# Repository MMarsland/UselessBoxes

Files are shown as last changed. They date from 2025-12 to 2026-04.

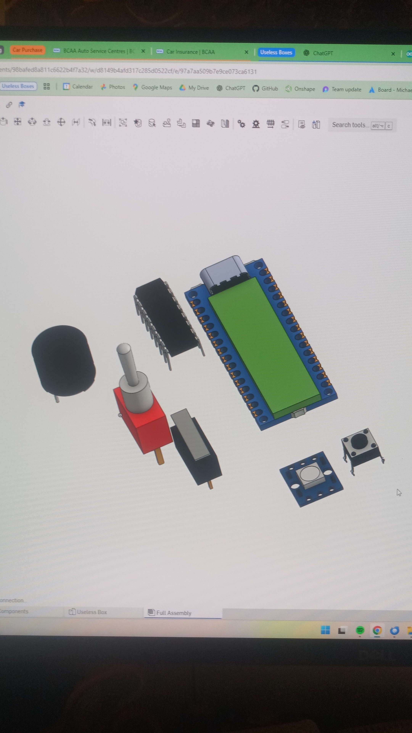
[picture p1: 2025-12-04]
docs/Publicity Images/IMG_20251023_234716_154.jpg

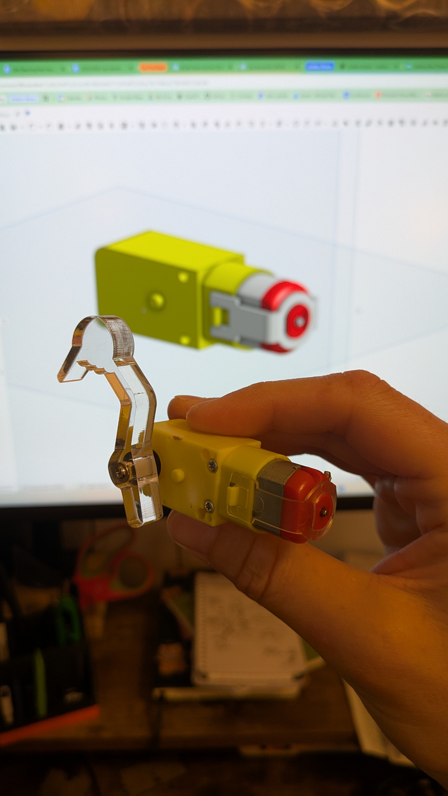
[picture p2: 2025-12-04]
docs/Publicity Images/PXL_20251024_221917552.jpg

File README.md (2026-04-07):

# 🟢 Project: UselessBoxes

A design for paired **UselessBoxes** that can be used to interact between friends.

---





---

## 📅 Project Info

- **Author:** Michael Marsland
- **Email:** mmarsland@mac.com
- **Date:** 10/10/2025
- **Revision:** 01/09/2026 - Alpha Dev
- **License:** Proprietary

**Project Description:**

The Useless Box project started a few years ago when my friend Trevor Johns gifted me a "Useless Box" for my birthday. A "Useless Box" is simply a small electro-mechanical device that sits on your desk and has a single switch on top. Upon flicking the switch, a small arm rises from the box to de-activate the switch, and then the cycle repeats.

This gift inspired the idea for a small IoT project where I could build Trevor and I each a similarly "Useless Box" for our desks except with the main change being, my switch would activate his arm to flick his switch off, and him turning his switch on would activate the arm on my box to turn my switch off.

Of course, I also took the opportunity to improve on the design of the box, adding LEDs, buzzers, settings buttons, and a sleeker look to make us the perfect desktop interactive toys. So while we're busy working on our other projects be it for work or personal interest, Trevor and I will be able to maintain our connection across the internet and still get on each others nerves even though we don't live in the same city anymore.

This project has been in the works for quite a while now and it is now in the late stages of assembly as I prepare to have it ready for his birthday this year (End of December).

I would like to see this project grow after the development of this first prototype so Trevor and I may collaborate on more iterations and maybe even add some of our other friends and create a larger interconnected network of slightly less useless "Useless Boxes" to all bother each other at once!

Let me know what you think and stay tuned for more updates!

---

## 🛠 Step 1: Installation

Currently using **Arduino Cloud** to set up the device as a "Thing" and a dashboard to control and monitor the variables.

### For Development:

I am currently developing in VSCode using the PlatformIO extension. I started in the ArduinoCloud Editor, and then copied UselessBoxes.ino, thingProperties.h, and arduino_secrets_*.h from there into my local ArduinoIDE. Then I installed all the required libraries from the ArduinoIDE (ArduinoIoTCloud, etc...), then I was able to make a project in PlatformIO in VS code and copy over the files. The modifications you must make to get it building in PlatformIO are:

1. Add these lines to platformio.ini
   ```
   lib_extra_dirs = ~/Documents/Arduino/libraries
   lib_ignore = WiFiNINA
   ```
2. Change Useless_Boxes.ino to Useless_Boxes.cpp
3. Write a "Useless_Boxes.h" with variable and function definitions (Ask an LLM for the header from the .cpp file)
4. Include `<Arduino>` and "Useless_Boxes.h" in Useless_Boxes.cpp
5. Include "arduino_secrets_*.h" in thingProperties.h

When running the code from this repository, all you should need to do is clone the repo, and then ensure you have Arduino ESP32 Boards by Arduino (2.0.18-arduino.5) installed in the ArduinoIDE, and the ArduinoIoTCloud by Arduino (2.8.0) library installed. Once these (And all dependencies) are installed in the ArduinoIDE, the project should build with PlatformIO in VSCode (Knock on Wood)

For Over The Air Uploads for new versions, follow this guide:

[Over The Air Uploads](./ota/ota-how-to-make-a-new-release.md)

---

## ⚡ Step 2: Assemble the Circuit

### 🧩 Components

- Arduino Nano ESP32 (3.3V logic)
- L293DNE H-Bridge motor driver
- DC motor
- SPDT switch (for direction)
- Momentary push button (for stop)
- 6V DC input (Potentially not necessary if USB-C power proves to be stable enough (Version 2))
- Jumper wires
- Common GND for all components

### ⚙️ Wiring Connections

## Useless Box Wiring Connections

## 🧠 Arduino Nano ESP32

| Pin | Connected To | Purpose / Notes |
| --- | --- | --- |
| **D2**  | L293D**Pin 2 (IN1)** | Motor direction control A (digital OUT).  |
| **D3**  | L293D**Pin 7 (IN2)** | Motor direction control B (digital OUT).  |
| **D4**  | L293D**Pin 1 (EN1)** | Motor enable / PWM speed control. |
| **D5**  | RGB LED**Blue** → 220Ω → LED **B Pin** | Blue channel (PWM). |
| **D6**  | RGB LED**Green** → 220Ω → LED **G Pin** | Green channel (PWM). |
| **D7**  | RGB LED**Red** → 220Ω → LED **R Pin** | Red channel (PWM). |
| **D8**  | SPDT Switch**Throw A** | Reads switch position (`INPUT_PULLUP`). |
| **D9**  | Limit Switch**NC Terminal** | Reads limit state (`INPUT_PULLUP`). |
| **D10** | Button**NC Terminal** | Reads button press (`INPUT_PULLUP`). |
| **D11** | Buzzer**+ Pin** | Buzzer output (tone / PWM). |
| **3V3** | — | Not used. |
| **GND** | All grounds (switches, LED common, buzzer −, L293D GND) | Shared ground. |

## 🐜 L293DNE (H-Bridge)

| L293D Pin | Function | Connected To | Notes |
| --- | --- | --- | --- |
| **Pin 1 (EN1)** | Enable 1 | Arduino**D4**  | PWM motor control  |
| **Pin 2 (IN1)** | Input 1 | Arduino**D2**  | Direction A |
| **Pin 7 (IN2)** | Input 2 | Arduino**D3**  | Direction B |
| **Pin 3 (OUT1)** | Motor A | Motor Terminal 1 | — |
| **Pin 6 (OUT2)** | Motor B | Motor Terminal 2 | — |
| **Pin 4, 5, 12, 13** | GND | Arduino**GND** | Common ground |
| **Pin 8 (VCC2)** | Motor Power | +6V external | Motor supply |
| **Pin 16 (VCC1)** | Logic Power | +5V supply | L293D logic supply |

## 🔀 SPDT Switch (2-position)

| Switch Terminal | Connected To | Purpose |
| --- | --- | --- |
| **Common (C)** | GND | Provides LOW when selected |
| **Throw A** | Arduino**D8** | Reads switch state |
| **Throw B** | — | Unused |

## 🧱 Limit Switch (Momentary)

| Terminal | Connected To | Purpose |
| --- | --- | --- |
| **C**  | GND | LOW when triggered |
| **NC** | Arduino**D9** (INPUT_PULLUP) | Default connected → LOW when limit reached |
| **NO** | — | Not used |

## 🔘 Button (Momentary)

| Terminal | Connected To | Purpose |
| --- | --- | --- |
| **C**  | GND | Pulls LOW when pressed |
| **NC** | Arduino**D10** (INPUT_PULLUP) | Reads button press |
| **NO** | — | Not used |

## 🔊 Buzzer

| Buzzer Pin | Connected To | Purpose |
| --- | --- | --- |
| **+**  | Arduino**D11** | Output for tone/PWM |
| **–** | GND | — |

## 🌈 RGB LED (Common Cathode recommended)

Each color pin requires a **220Ω resistor**.

| LED Pin | Connected To | Notes |
| --- | --- | --- |
| **R (Red)** | 220Ω → Arduino**D7** | PWM capable  |
| **G (Green)** | 220Ω → Arduino**D6** | PWM capable  |
| **B (Blue)** | 220Ω → Arduino**D5** | PWM capable  |
| **Common Cathode** | 3.3v | Shared power |

---

## 💻 Step 3: Load the Code

Upload the code contained in this sketch onto your board via PlatformIO in VSCode

### 📂 Folder Structure

- [README.md](README.md) — Project README and Instructions (This File)
- [.gitignore](.gitignore) — Git Ignore
- [sketch.json](sketch.json) — Something to do with Arduino Cloud
- [docs/](docs/) — Documentation Folder (Schematics)

  - [UselessBoxes.fzz](docs/UselessBoxes.fzz) — Fritzing Circuit Diagram
- [Useless_Boxes/](Useless_Boxes/) — Arduino sketch folder

  - [Useless_Boxes.ino](Useless_Boxes/Useless_Boxes.ino) — Main Arduino file
  - [arduino_secrets.h](Useless_Boxes/arduino_secrets.h) — Secrets for the Devices and Arduino Cloud
  - [thingProperties.h](Useless_Boxes/thingProperties.h) — Properties for Arduino Cloud

---

## 🤝 Contributing

To contribute to this project, please contact:

**Michael Marsland**
Email: mmarsland@mac.com

---

## 📝 Bill of Materials (BOM) (TODO)

| ID | Part name | Part number | Quantity |
| -- | --- | --- | --- |
| | Arduino Nano ESP32 | | 1 |
| | RGB Led | | 1 |
| | 220 Ohm Resistors | | 3 |
| | Piezo Buzzer | XYDZ | 1 |
| | Button | | 1 |
| | Limit Switch | | 1 |
| | SPDT Switch | | 1 |
| | H-Bridge | L293DE | 1 |
| | Barrel Jack Connector (Optional) | | 1 |
| | Motor, Gear Box, and Armature from Useless Box | | 1 |
| | 6V/0.83A Power Supply (Optional) | | 1 |
| | Wires (Approx 25) | | ~25 |
| | M2x6 Bolts & M2 Nuts | | 6 |
| | Custom 3D Printed Housing | | 1 |
| | | | |
| | | | |

---

## 🛣️ Project Roadmap

A step-by-step roadmap to finish the UselessBoxes project, from platform selection to final hardware.

### 🖥️ SOFTWARE

#### Decide on the Interconnection Platform

- Evaluate options:
  - Arduino Cloud
  - Thinger.io
  - Your own website with custom backend
- Consider:
  - Free tier limitations
  - Data synchronization capabilities
  - Ease of integration with Arduino Nano ESP32

**Decided to stick with Arduino Cloud for V1**
It will highly simplify the steps required to get a functioning system running.
And it will be free for up to two devices and 5 variables per device.
This should be enough to control the motors and even a few settings.
I can also determine a way to adjust settings on the device (A button perhaps and detailed procedures).
I can upgrade from Arduino Cloud to a different free option in the future such as using my website or a serverless implementation in V2.

#### Ensure Interdevice Communication and Functionality

* [X] Test interactions between paired UselessBoxes
* [X] Verify:
  * [X] State changes propagate correctly
  * [X] Motors respond as expected
  * [X] Dashboard reflects real-time updates

### ⚙️ HARDWARE

#### Design Hardware

* [X] Will need to decide on final wiring, how will the wires connect, where/how will the eletronics be seated
* [X] Prototype and design 3D printed housing
* [X] Ensure components can fit and function
* [X] Make design simple, and practical for desk use

#### Solder Components

* [X] Power Jack
* [X] Switch
* [X] Limit Switch
* [X] Buzzer
* [X] LED
* [X] H-Bridge
* [X] Button
* [X] Motor

##### Solder to Arduino

* [X] Power Jack
* [X] Switch
* [X] Limit Switch
* [X] Buzzer
* [X] LED
* [X] H-Bridge
* [X] Button
* [X] Solder all power to jack
* [X] Solder all ground to jack

#### Finalize Hardware

* [X] Secure all components in the box
* [X] Ensure wiring is neat and safe
* [X] Test full functionality before duplicating

#### Build the Second Box

* [X] Replicate hardware and software setup
* [X] Connect to the same platform
* [X] Test intercommunication between the two boxes

#### Tweaks / Features

* [X] Print and assemble final box in V5 with correct color
* [X] Ensure the correct state is loaded when turning on the box (I.e. LED)
* [X] Update munu items as we scroll through them
* [X] Play Buzzer sound Previews as we scroll through them (Loop should end quickly)
* [X] Make the menu navigation obvious with beeps or lights
* [ ] Add more buzzer and led patterns (+ make it easy and modular to add more custom buzzer and led patters)
* [ ] Clean up code (Organize where variables and defaults are declared)

#### Deployment Features

* [X] (Optional) Setup Over-The-Air updates so the software can be modified
* [X] Setup wifi connection process so that devices can be easily set up

##### ✅ Notes

- Based on testing, it appears the motor can run on board USB-C power without crashing the board so the 6V barrel jack source could be dropped in Version 2 and the whole box could be powered solely with the USB-C cable.

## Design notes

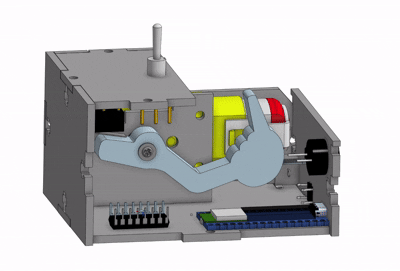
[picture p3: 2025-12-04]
docs/Publicity Images/OnShape Useless Box Video.gif

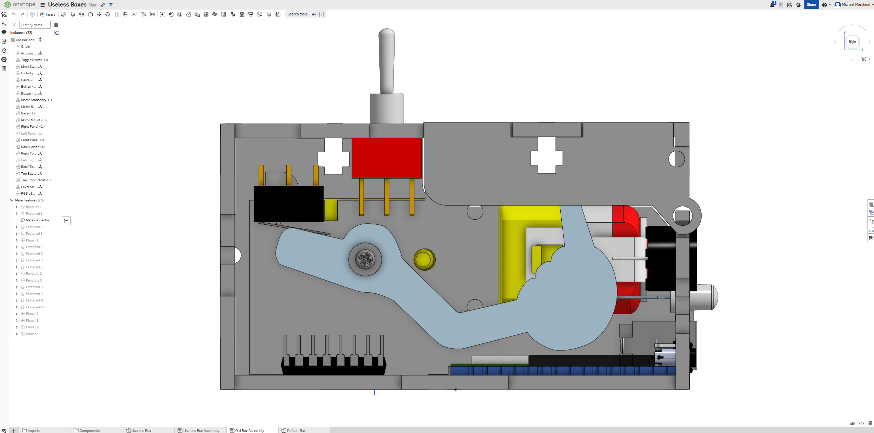
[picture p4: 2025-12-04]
docs/Publicity Images/Onshape Useless Box.png

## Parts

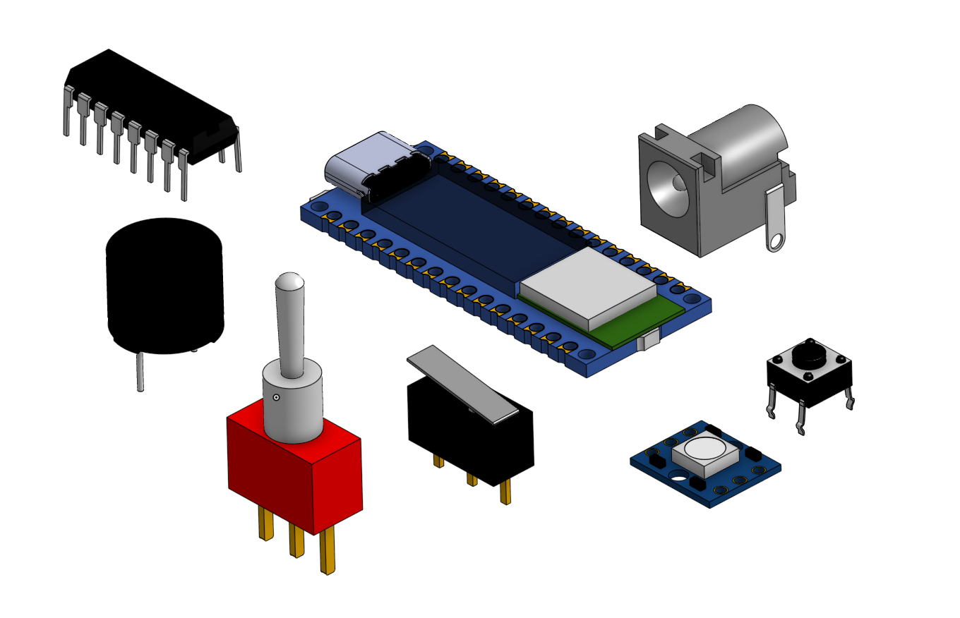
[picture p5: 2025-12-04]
docs/Publicity Images/Components.png

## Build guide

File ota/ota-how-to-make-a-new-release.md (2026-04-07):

## OTA update steps for this project

Now that GitHub Releases OTA is wired in, the flow is:

---

## 1) Make your firmware changes

Edit the code as needed.

---

## 2) Bump the firmware version

In [Useless_Boxes.cpp](vscode-file://vscode-app/c:/Users/mmars/AppData/Local/Programs/Microsoft%20VS%20Code/cfbea10c5f/resources/app/out/vs/code/electron-browser/workbench/workbench.html), update:

to the new version, for example:

> 114 : constexpr char CURRENT_FW_VERSION[] = "v1.0.1"; // Bump this for each release

---

## 3) Run the Powershell OTA Scropt

Run this command which handles the release:

```
powershell -ExecutionPolicy Bypass -File "c:\Users\mmars\Desktop\Personal\Storage Hold\Code\UselessBoxes\PlatformIO\scripts\release_ota.ps1" -CommitManifest -Push -CreateGitHubRelease
```

---

## Quick checklist

### Every OTA release:

1. Change code
2. bump [CURRENT_FW_VERSION](vscode-file://vscode-app/c:/Users/mmars/AppData/Local/Programs/Microsoft%20VS%20Code/cfbea10c5f/resources/app/out/vs/code/electron-browser/workbench/workbench.html)
3. build both envs
4. upload both `.bin` files to a GitHub Release
5. update [michael.txt](vscode-file://vscode-app/c:/Users/mmars/AppData/Local/Programs/Microsoft%20VS%20Code/cfbea10c5f/resources/app/out/vs/code/electron-browser/workbench/workbench.html) and [trevor.txt](vscode-file://vscode-app/c:/Users/mmars/AppData/Local/Programs/Microsoft%20VS%20Code/cfbea10c5f/resources/app/out/vs/code/electron-browser/workbench/workbench.html)
6. push manifest changes

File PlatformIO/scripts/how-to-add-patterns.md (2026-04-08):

# How to add new LED and buzzer patterns

This folder supports a **simple file-based workflow** for creating new patterns.
After a successful add, the template files are automatically reset back to starter examples.

---

## LED pattern workflow

### 1) Edit `scripts/led_pattern.txt`

Use a single file with the pattern name on a `name:` line.
Everything below that is treated as the renderer body.

Example:

```txt
name: Ocean Pulse

const float cycle = (now % 2500UL) / 2500.0f;
const float wave = (sin(cycle * TWO_PI) + 1.0f) * 0.5f;
const uint8_t blue = static_cast<uint8_t>(40.0f + (wave * 215.0f));
const uint8_t green = static_cast<uint8_t>(10.0f + (wave * 90.0f));
return makeRGBColor(10, green, blue);
```

### 2) Preview safely (recommended)

```powershell
.\.venv\Scripts\python.exe scripts\add_led_pattern.py --dry-run
```

### 3) Add the pattern for real

```powershell
.\.venv\Scripts\python.exe scripts\add_led_pattern.py
```

### 4) What happens next

- The new LED pattern is added to the firmware files.
- `led_pattern.txt` is reset back to the starter example template.

---

## Buzzer pattern workflow

### 1) Edit `scripts/buzzer_pattern.json`

Add a name, a `steps` array, and a `loops` flag:

```jsonc
{
  "name": "Victory Chime",
  "steps": [
    { "frequency": 900,  "duration": 100, "pauseDuration": 60 },
    { "frequency": 1200, "duration": 120, "pauseDuration": 40 },
    { "frequency": 1500, "duration": 160, "pauseDuration": 0 }
  ],
  "loops": false
}
```

### 2) Preview safely (recommended)

```powershell
.\.venv\Scripts\python.exe scripts\add_buzzer_pattern.py --dry-run
```

### 3) Add the pattern for real

```powershell
.\.venv\Scripts\python.exe scripts\add_buzzer_pattern.py
```

### 4) What happens next

- The new buzzer pattern is added to the firmware files.
- `buzzer_pattern.json` is reset back to the starter example template.

---

## Comment support

The scripts accept:

- standard JSON
- Python-style single-quoted literals
- comment lines using `//`, `#`, or `/* ... */`

So you can keep example blocks commented out in the template files.

---

## Tips

- Use unique names so patterns are not added twice.
- In `led_pattern.txt`, keep only the `name:` line plus the renderer body — **do not** include the full function signature.
- Use `--dry-run` first if you want to validate before changing firmware files.
- After adding a pattern, build/upload as normal and select it from the menu.

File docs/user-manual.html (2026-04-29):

Official User Manual

# Useless Box

Basic setup and everyday operation guide for your connected paired Useless Box system.

Power: Barrel Jack or USB-C Wi-Fi Connected Pairing Customizable RGB, Buzzer, Motor

## 1. Product Overview

The Useless Box is a playful, internet-connected mechanical device designed to interact with a paired box. When connected to Wi-Fi, each box can influence the other box's active or inactive state.

Each unit includes:

- A physical switch for local activation and deactivation.
- RGB lighting effects for active and inactive states.
- Buzzer sound patterns for activation feedback.
- A rear settings button for menu navigation and customization.

## 2. Powering The Box

1

Connect power using either the provided Barrel Jack connector or a USB-C cable.

2

Wait for startup. The box will attempt to connect to its configured home Wi-Fi automatically.

3

After successful Wi-Fi connection, the box begins interacting with the paired box.

If the box fails to connect to Wi-Fi, there may currently be no visible status indicator. For support, contact Michael Marsland.

## 3. Basic Use

A

Push the front switch forward to activate the box.

B

Push the switch back to deactivate your box locally.

C

Keeping the switch back leaves your box inactive, which is useful when you do not want to be disturbed.

## 4. Rear Button Menu Controls

- Short press in main menu: move to the next setting.
- Long press in main menu: enter that setting submenu.
- Short press in submenu: cycle through available options.
- Long press in submenu: confirm current option and return to main menu.

Tip: Use short presses to browse quickly, then long press only when you want to save.

## 5. Settings Directory

Menu Item | Description
1. Active RGB Colour | Chooses the RGB pattern shown while your box is active.
2. Inactive RGB Colour | Chooses the RGB pattern shown while your box is inactive.
3. RGB Brightness | Adjusts LED brightness from 0% to 100% in 10% increments.
4. Active Buzzer Sound | Selects buzzer pattern used when the box becomes active.
5. Inactive Buzzer Sound | Selects buzzer pattern used when the box becomes inactive.
6. Motor Speed | Adjusts motor power from 40% to 100% in 10% increments.
7. Solo Mode | Toggles standalone operation On or Off.

## 6. Behavior Notes

- The box uses separate RGB behavior for active vs inactive states.
- The buzzer can be set to short one-time effects or looping patterns.
- Settings are stored on the box so your choices remain after restart.

## 7. Solo Mode

Solo Mode lets the box behave like a traditional standalone Useless Box. While Solo Mode is enabled, local switch actions do not affect the paired box.

## 8. Programming / Firmware Updates

To program the box, connect it to a computer using USB-C and follow the project instructions in the repository README.md.

Enjoy USEing your USELESS BOX.

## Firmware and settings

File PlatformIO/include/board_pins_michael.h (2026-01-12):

#pragma once
// Pin mappings for MICHAEL board
#ifndef BOARD_PINS_MICHAEL_H
    #define BOARD_PINS_MICHAEL_H

    // Box name (moved here from arduino_secrets)
    #define BOX_NAME "MICHAEL"

    constexpr int EN1 = 2;           // Motor enable (PWM capable)
    constexpr int IN1 = 3;           // Motor direction A
    constexpr int IN2 = 4;           // Motor direction B
    constexpr int RGB_R = 6;         // LED Red
    constexpr int RGB_G = 7;         // LED Green
    constexpr int RGB_B = 5;         // LED Blue
    constexpr int SWITCH_PIN = 8;    // SPDT switch
    constexpr int LIMIT_PIN = 9;     // Limit Switch
    constexpr int BUTTON_PIN = 10;   // Settings button
    constexpr int BUZZER_PIN = 11;   // Buzzer

#endif // BOARD_PINS_MICHAEL_H

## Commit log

2025-10-09 initial commit (Downloaded files from Arduino Cloud)
2025-10-09 Add basic motor control
2025-10-09 Electronic Motor Control with Switch, button and H-Bridge (Hardware Control)
2025-10-10 Wiring Diagram
    [UselessBoxes.fzz]
2025-10-10 Switch to Digital Software control of the motor
    Update Project Structure
    [UselessBoxes.fzz]
2025-10-10 docs: Update wiring diagram
    [UselessBoxes.fzz]
2025-10-16 docs: Decide to stick with Arduino Cloud
2025-10-17 Enable Device Intercommunication
    - Set up both boards
    - Sync variable with arduino cloud
    - Add button for settings menu
2025-12-04 Change Pin Numbers for Prototype Board
2025-12-05 Fix RGB LED and Buzzer Control
2025-12-05 Improve LED, Buzzer, and overall Menu Behavior
2026-01-08 Update defaults and pin numbers for Hardware 1
2026-01-10 Setup for Trevor's Box - Add Board Pins Files and Arduino Secret Files and Environments for each board - Modify to final behaviour type - Begin work on duty cycle to slow down motor
2026-01-10 Broken PWM Motor Enable
2026-01-12 Have PlatformIO Import ArduinoIoTCloud Locally isntead of using ArduinoIDE
2026-01-12 Modify Motor to run normally, hopefully I can fix the bounce problem in the hardware
    [board_pins_michael.h]
2026-01-13 Add Motor Speed Control with On/Off Timing (PWM Style)
2026-01-13 Menu Nav and Buzzer Improvements [x] Ensure the correct state is loaded when turning on the box (I.e. LED) [x] Update munu items as we scroll through them [x] Play Buzzer sound Previews as we scroll 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
2026-04-08 Add new led and buzzer adding method
2026-04-08 Add new Buzzer and LED patterns
